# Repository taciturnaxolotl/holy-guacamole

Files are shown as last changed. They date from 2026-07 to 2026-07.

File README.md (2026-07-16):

# Holy Guacamole 🥑



the assembled cad

This is a meltybrain style combat robot that's main weapon is simply its own spinning kinect energy. The BOM is on a google sheet [here](https://docs.google.com/spreadsheets/d/1paAJ0Wakvn5M726pM15FUGLVGKdC47_Wt41PN1yA9PQ/edit?gid=0#gid=0) and the CAD is done in onshape and available [here](https://cad.onshape.com/documents/a046eeb92ff2319e557090a2/w/6774deed54414bae93c63cc1/e/4d0675cbf797ff5c6c8f60bb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)

The canonical repo for this is hosted on tangled over at [`dunkirk.sh/holy-guacamole`](https://tangled.org/dunkirk.sh/holy-guacamole)

| | |
|---|---|
| render 4 | render 3 |
| render 2 | render 1 |

<p align="center">
    
</p>

<p align="center">
    <i><code>&copy; 2026-present <a href="https://dunkirk.sh">Kieran Klukas</a></code></i>
</p>

<p align="center">
  
  
</p>

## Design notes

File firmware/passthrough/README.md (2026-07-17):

# ELRS Passthrough (RP2350)

A **temporary tool firmware** that turns the XIAO RP2350 into a Betaflight-style
serial passthrough bridge, so you can flash or configure the ELRS receiver
wired to `uart0` using the **ExpressLRS Configurator** — no USB-to-serial
adapter, no transmitter, no WiFi.

The receiver is the only thing on `uart0` (GPIO0 = TX → RX's RX, GPIO1 = RX ←
RX's TX, from `../include/hw_pins.h`), which is exactly where a flight
controller sits. This firmware makes the RP2350 answer like one.

## How it works

1. Presents a USB CDC serial port (raw, no console).
2. Emulates the minimal Betaflight CLI that `BFinitPassthrough.py` checks:
   `#`, `get serialrx_provider|inverted|halfduplex|rx_spi_protocol`, `serial`,
   and `serialpassthrough`.
3. On `serialpassthrough` it becomes a transparent USB↔`uart0` bridge and
   mirrors the host's baud onto `uart0`.
4. The Configurator then sends the ROM training burst + the CRSF
   reboot-to-bootloader command through the bridge, and esptool flashes the
   receiver over the same wire.

Until passthrough is active it does **not** forward `uart0` → USB, so the
receiver's CRSF chatter can't corrupt the CLI handshake.

## Build

```bash
# from repo root, inside the firmware nix shell
nix develop ./firmware --command bash -c \
  'cmake -B firmware/passthrough/build -S firmware/passthrough \
     -DPICO_PLATFORM=rp2350 -DPICO_BOARD=pico2 && \
   cmake --build firmware/passthrough/build -j'
```

Output: `firmware/passthrough/build/elrs_passthrough.uf2`.

## Use it

1. **Flash the tool** (reboots the running board into BOOTSEL automatically):
   ```bash
   picotool load -x firmware/passthrough/build/elrs_passthrough.uf2
   ```
2. Open the **ExpressLRS Configurator**, pick your receiver target
   (e.g. BetaFPV 2.4GHz RX), Flashing Method = **BetaflightPassthrough**,
   select the RP2350's serial port, and Flash. (Or use it just to open the
   web/settings if you only want to reconfigure.)
3. **Restore the flight firmware** when done:
   ```bash
   picotool load -x firmware/build/holy_guacamole.uf2
   ```

## Notes

- This image is standalone; it never runs the flight-control loop.
- Baud is followed live via `tud_cdc_line_coding_cb`, so esptool baud changes
  are handled.
- Verified to build and enumerate; the esptool handshake is best confirmed by
  an actual flash attempt against the receiver.

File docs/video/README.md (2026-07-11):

# Holy Guacamole — explainer video

A 3Blue1Brown–style explainer on how meltybrain combat robots work, built in
Motion Canvas. Voiceover-driven, so timing is intentionally loose.

## Run it

```bash
bun install
bun start      # Motion Canvas editor at http://localhost:9000
```

Scrub the timeline in the editor; render from there.

## How it's built

The whole video is **one continuous scene** (`src/scenes/main.tsx`). There are
no cuts. A single persistent robot and a camera-able `world` are handed from
beat to beat, and each beat *transforms* what's on screen rather than replacing
it. That continuity is the 3b1b feel.

- `src/theme.ts` — Manim palette (near-black stage, signature blue, warm
  yellow for "look here"). Fonts are placeholder stacks — swap before final render.
- `src/lib.tsx` — the `Stage` (view + world + robot + a `shared` handoff bag),
  camera helpers (`zoomTo`, `resetCamera`), and builders (`tex`, `label`, `vector`).
- `src/components/MeltyRobot.tsx` — the robot as a minimal stroked diagram.
- `src/beats/*.tsx` — the seven beats, in order.

## The arc (`src/beats/`)

1. `intro` — the melty pops in and starts spinning; "this is a melty"
2. `weapon` — the whole body is the weapon; no constant forward
3. `problem` — a body-fixed heading vector; "forward" turns with the robot
4. `translation` — kick a motor at the same heading each spin; kicks → a glide
5. `centrifugal` — camera glides to a rim sensor; a = ω²r → ω → θ = ∫ω dt
6. `drift` — a naive integrator's estimate lags; live error readout climbs
7. `solution` — an EKF's belief (bell curve) predicts, then sharpens on the
   sensors until the estimate locks onto the true heading

Reorder or trim beats in `main.tsx`. To add one, drop a
`function* name(s: Stage)` in `src/beats/` and slot it into the sequence.

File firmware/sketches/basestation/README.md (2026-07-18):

# Basestation RF Beacon (Arduino)

A stationary ESP-NOW transmitter for the meltybrain RSSI heading system. It
does one thing: broadcast packets as fast as the radio allows so the spinning
robot can measure their RSSI and derive heading from the phase.

## What it is (and isn't)

- **Is:** a dumb beacon. WiFi + antenna + power, nothing else.
- **Isn't:** it does **not** read RSSI, does **not** connect to an ELRS
  receiver, and has **no** UART. All RSSI measurement and heading math happen
  on the robot (`esp-rssi/`).

## Hardware

- **Board:** Seeed XIAO ESP32-C6
- Just needs power and its antenna. No other wiring.
- The onboard user LED (GPIO15) heartbeats ~1 Hz while running, so a blinking
  LED means the basestation is powered and beaconing.
- Just needs power and its antenna. No other wiring.

## Protocol

ESP-NOW broadcast on channel 1, no encryption, no ACK:

- Payload: `magic` byte (`0xB6`) + rolling `uint32` sequence counter
- The payload content is irrelevant to the heading math — that only uses the
  **received RSSI**. The sequence number is purely for drop detection.

Channel and magic byte must match the robot receiver in `esp-rssi/`.

## Flashing (Arduino IDE)

1. Install the **ESP32 boards package** (Boards Manager → "esp32" by
   Espressif). Any recent version works for the beacon.
2. Open `basestation.ino`.
3. Select board **ESP32C3 Dev Module** (or "XIAO_ESP32C3").
4. Select the serial port, then Upload.

Or with `arduino-cli` (from this sketch folder):

```bash
arduino-cli compile --fqbn esp32:esp32:esp32c3 .
arduino-cli upload  --fqbn esp32:esp32:esp32c3 -p <PORT> .
```

## Where it sits in the system

```
[ basestation ] --ESP-NOW broadcast--> [ robot ESP32-C3 (esp-rssi) ]
   (this repo)                              measures RSSI per packet,
                                            runs heading pipeline,
                                            sends stats to RP2350 over UART
```

The ELRS control link is entirely separate and lives on the RP2350 — the
basestation has nothing to do with it. See `docs/firmware.md` for the full
system layout.

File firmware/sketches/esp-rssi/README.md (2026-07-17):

# ESP32-C3 RSSI Heading Receiver (Arduino)

Onboard the spinning robot. Receives beacon packets via ESP-NOW broadcast,
measures the **received signal strength of each packet** (which rises and falls
once per revolution as the robot spins), runs autocorrelation + PLL heading
estimation, and streams results over UART to the RP2350 flight controller.

The heading signal is the radio's measured RSSI of the received packet, not
anything carried in the payload.

## Requirements

- **ESP32 Arduino core 3.0 or newer.** The receive callback needs the
  `esp_now_recv_info_t` signature to read per-packet RSSI (`rx_ctrl->rssi`).
  Core 2.x only exposes the MAC + payload and cannot read RSSI here.

## Hardware

- **Board:** ESP32-C3 (Seeed XIAO ESP32-C3 or any ESP32-C3)
- **UART TX:** GPIO4 → RP2350 GPIO23/SWDIO
- **UART RX:** GPIO5 ← RP2350 GPIO24/SWDCK
- **Baud rate:** 115200 (Serial1)

## Sketch layout

Arduino compiles every `.c`/`.cpp` in the sketch folder, so the ported RSSI
pipeline lives right alongside the sketch:

```
esp-rssi/
  esp-rssi.ino        # WiFi + ESP-NOW + UART glue
  rssi_heading.c/.h   # pipeline top level: interp + autocorr + edge PLL
  rssi_interp.c/.h    # resample RSSI onto a uniform time grid
  autocorr.c/.h       # rotation-period acquisition
  edge_pll.c/.h       # edge-triggered phase lock
```

## UART protocol

Binary frames at ~100 Hz:

```
[0x55 0xAA] [theta_f32] [omega_f32] [locked_u8] [rssi_i8]
  header      rad [0,2pi)  rad/s       0/1          dBm
```

Total: 12 bytes per frame.

## Flashing (Arduino IDE)

1. Install the **ESP32 boards package** 3.0+ (Boards Manager → "esp32").
2. Open `esp-rssi.ino`.
3. Select board **ESP32C3 Dev Module** (or "XIAO_ESP32C3"), pick the port,
   Upload.

Or with `arduino-cli` (from this sketch folder):

```bash
arduino-cli compile --fqbn esp32:esp32:esp32c3 .
arduino-cli upload  --fqbn esp32:esp32:esp32c3 -p <PORT> .
```

The USB serial prints 1 Hz diagnostics (lock state, omega, dropped beacons);
the heading frames go out on Serial1 to the RP2350.

## Transmitter Side

The stationary basestation (`basestation/`) broadcasts beacon packets on
ESP-NOW channel 1, no encryption. Each packet is a `{magic=0xB6, seq}` struct;
this receiver rejects anything without the magic byte and uses `seq` only to
count dropped packets. Channel and magic byte must match on both ends.

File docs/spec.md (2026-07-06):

# Holy Guacamole — Carrier PCB Specification

**Document status:** Draft v1.3c — updated to match current `circuit.py` Rev A schematic: solder-down ELRS receiver `U7`, 3S-ready VBUS, protection diodes documented  
**Robot:** Holy Guacamole — 1lb meltybrain antweight, MRCA full-combat  

---

## Overview

The carrier PCB is a purpose-built board for a Seeed XIAO RP2350 module. It is **not** a bare-RP2350 compute board: the XIAO provides the RP2350, flash, USB, crystal, and onboard 3.3V regulator. The carrier provides power conditioning, sensors, connectors, and robot-specific IO.

Primary carrier jobs:

- Mount the XIAO RP2350 flat as an SMD/castellated module; no XIAO pin headers.
- Generate a local regulated 5V rail from the switched LiPo bus (2S nominal, 3S-ready to 12.6V) using an AP63205 fixed-5V buck regulator.
- Use the XIAO 3.3V rail for IMUs, the SPI-loaded chip-select latch, analog sensing, and control logic; power the solder-down BetaFPV ELRS Lite receiver (`U7`) from the carrier 5V rail per its vendor spec.
- Route SPI to one inner LSM6DSV320X 6-axis/high-G IMU and two outer H3LIS331DL high-G accelerometers.
- Use a SN74HC595PWR SPI-loaded latch for IMU chip-selects and SK9822 LED-output enable; firmware blanks the latch outputs while shifting a new select byte.
- Connect to the Repeat AM32 Dual Brushless Drive ESC using two direct bidirectional DSHOT/EDT lines.
- Keep independent battery voltage sensing on the carrier.
- Rely on AM32 bidirectional DSHOT / EDT for motor eRPM/current/voltage telemetry; no external Kelvin shunt in Rev A.
- Provide a dedicated orange 2-3S TinySLED meltybrain heading output using XIAO edge pin D1/A1 and one MOSFET low-side switch; no underside XIAO GPIOs are used for runtime IO.
- Retain chained top/bottom SK9822 RGB status LEDs for boot/error/mode indication and expose only essential VBAT/SWD/GND test pads.

The PCB mounts near the chassis centre. Final IMU coordinates must be measured from the actual chassis rotation centre and copied into firmware calibration constants.

---

## Current schematic reference designators

These names match the current SKiDL schematic in `circuit.py`.

| Ref | Function |
|---|---|
| `U1` | Seeed XIAO RP2350 SMD module |
| `U2` | AP63205 fixed 5.0V buck regulator |
| `U3` | SN74HC595PWR SPI-loaded chip-select / LED-enable latch |
| `U4` | LSM6DSV320XTR inner 6-axis / high-G IMU |
| `U5`, `U6` | H3LIS331DLTR outer high-G accelerometers |
| `U7` | BetaFPV ELRS Lite receiver, solder-down module footprint |
| `U8`, `U9` | SN74AHCT1G125 3.3V-to-5V SK9822 data/clock buffers |
| `U10`, `U11` | SK9822-EC20 2×2mm addressable status LEDs, top and bottom chained pair |
| `Q1` | AO3402 low-side MOSFET for orange TinySLED heading LED |
| `J1` | Switched 2S/3S LiPo / VBUS carrier power input |
| `J2` | External orange 2-3S TinySLED heading LED connector |
| `J4` | Repeat AM32 dual ESC signal connector |
| `D2` | SMAJ15CA bidirectional TVS across VBUS at power entry |
| `D3`, `D4` | PESD5V0V1BB ESD clamps on DSHOT1/DSHOT2 at J4 |

`J3` piezo and `J5` from older revisions are retired and not present in the current Rev A schematic. The older `J6` receiver fly-lead connector is replaced by the solder-down `U7` receiver footprint.

---

## Physical constraints

| Parameter | Value |
|---|---|
| Board shape | Rectangular with rounded corners |
| Board dimensions | **40mm × 50mm** (width × length) |
| Front direction | 50mm axis is front-to-back; front = top edge in KiCad |
| Max board thickness | 1.0mm preferred; standard 1.6mm may violate chassis Z budget |
| Max component height above board | 2.5mm nominal, set by XIAO module height |
| Mounting | 4× M3 brass heat-set inserts in chassis, M3×6 SHCS from below; holes at four corners inset ~2.5mm from edges |
| Connector exits | J2 heading LED on front (top) edge; J1 power and J4 ESC signal on rear (bottom) edge; all via 26AWG silicone fly-leads on compact non-relief 0.25sqmm SolderWire pads, epoxied after soldering; 16AWG stays in the off-board battery/switch/ESC loop and never lands on the carrier |
| Operating temperature | 0–60°C ambient expectation, with local motor/ESC heating nearby |
| Vibration/impact | Extreme; reinforce heavy/tall components and wire exits with epoxy or strain relief |

### Board coordinate system

KiCad origin at top-left corner of the 40×50mm rectangle. Board center is at (20mm, 25mm). The +Y axis points toward the rear edge; the front/heading edge is at Y=0.

Mounting hole centers (4× M3):

| Hole | X (mm) | Y (mm) |
|---:|---:|---:|
| MH1 | 2.5 | 2.5 |
| MH2 | 37.5 | 2.5 |
| MH3 | 2.5 | 47.5 |
| MH4 | 37.5 | 47.5 |

### IMU placement on rectangular board

The 40×50mm rectangle provides ample clearance for the original IMU radii. All three IMU centroids fit well within the board outline with room for solder mask, routing, and connector pads.

Rev A layout rule:

- Board center at (20, 25) is the rotation reference point.
- Place IMUs at the nominal radii and angles listed below.
- Firmware must use the **measured** post-layout IMU coordinates, not just nominal values from this document.

---

## Module: Seeed XIAO RP2350

**Reference:** `U1`  
**Datasheet / getting started:** https://wiki.seeedstudio.com/xiao_rp2350_getting_started/

| Parameter | Value |
|---|---|
| Dimensions | 21 × 17.5 × 2.5mm |
| Mounting | Castellated SMD pads, soldered flat to carrier; no pin headers |
| Mechanical retention | Small epoxy fillet at four corners after soldering |
| CPU | RP2350, dual Cortex-M33 @ 150MHz, hardware FPU |
| Flash | 4MB W25Q32 onboard; no carrier flash required |
| Crystal | 12MHz onboard; no carrier crystal required |
| 5V input | XIAO `5V/VBUS` pad fed from carrier AP63205 5V rail |
| 3.3V output | XIAO 3.3V rail powers carrier logic/sensors; do not exceed XIAO 3.3V output budget |
| USB-C | Onboard; use for bench programming/config, not combat field wiring |
| SWD | Break out SWDIO/SWDCLK/GND to test pads |

Firmware workload intent:

| Core | Responsibility |
|---|---|
| Core 0 | IMU SPI DMA / sensor fusion / heading EKF / RPM estimation |
| Core 1 | CRSF, DSHOT/EDT, drift control loop, telemetry/status |

---

## Power architecture

Rev A keeps an independent controller buck regulator. The Repeat AM32 dual ESC BEC is **not connected** to the carrier 5V rail.

```text
2S LiPo (3S-ready bus)
  -> Fingertech / main switch
      -> switched battery bus
          -> Repeat AM32 dual ESC power pads
          -> carrier J1 VBUS/GND
              -> D2 SMAJ15CA TVS clamp at power entry
              -> AP63205 fixed 5.0V buck
                  -> 5V rail
                      -> XIAO 5V/VBUS pad
                      -> chained top/bottom SK9822 status LEDs + AHCT buffers
                      -> U7 BetaFPV ELRS Lite receiver 5V pad (solder-down)
                  -> XIAO onboard 3.3V regulator
                      -> LSM6DSV320X + H3LIS331DL IMUs
                      -> SN74HC595 chip-select latch
                      -> analog clamps / control logic
              -> J2 pin 1 TinySLED VBUS feed
                  -> external orange 2-3S TinySLED
                  -> J2 pin 2 HEAD_SW
                  -> Q1 AO3402 low-side switch to GND
```

### ESC BEC policy

The Repeat AM32 Dual ESC includes a 5V BEC, but Rev A leaves it isolated. Do **not** tie the ESC BEC directly to the carrier AP63205 5V rail.

Reasons to keep the carrier buck in Rev A:

- Known 5V source on the controller board.
- Better controller independence if the ESC resets or current-limits hard.
- Avoids importing motor-switching/BEC noise into IMU and analog domains until measured.
- Simpler debugging: battery into `J1` means carrier power is deterministic.

Possible Rev B change:

- Remove/DNP AP63205 buck and use ESC BEC only, **or** add a solder-jumper / ideal-diode power selector.
- Before doing that, confirm ESC BEC current rating, voltage tolerance, startup behavior, and noise under motor load.

### Buck converter: AP63205

**Reference:** `U2`  
**Part:** Diodes Inc. AP63205WU-7, fixed 5.0V, LCSC `C2071056`

| Parameter | Value |
|---|---|
| Package | TSOT-23-6 |
| Input voltage | 3.8–32V part capability; design VBUS is 2S LiPo 6.0–8.4V nominal, 3S-ready to 12.6V |
| Output voltage | Fixed 5.0V; FB pin connects to 5V, no feedback divider |
| Output current | 2A device rating; actual board load is far lower unless external LEDs are overdriven |
| Inductor | 4.7uH, Bourns SRP4020TA-4R7M / LCSC `C2041623` in current schematic |

Required local passives in current schematic:

| Ref | Value | Function |
|---|---|---|
| `C1` | 22uF | VBUS input bulk, rated at least 25V |
| `C2` | 100nF | High-frequency VIN bypass close to U2 VIN/GND |
| `C3` | 100nF | Bootstrap capacitor from BST to SW |
| `C4`, `C5` | 22uF each | 5V output capacitance near L1/U2 return path |
| `C6` | 10uF | 3.3V bulk near sensor/control load cluster |

Power-entry protection in current schematic:

| Ref | Part | Function |
|---|---|---|
| `D2` | SMAJ15CA, LCSC `C110044` | Bidirectional 15V-standoff TVS across VBUS/GND at J1; clamps below the AP63205 32V input rating with margin for 3S |

Layout requirements:

- Place `C1`/`C2` tight to U2 VIN/GND.
- Keep the `SW` copper area compact.
- Keep the buck switch node and inductor away from IMUs, CRSF, VBAT sense, and heading LED control/test nodes.
- Use wide copper for VBUS and 5V where LED pulses can draw peak current.

---

## IMU array: 1× LSM6DSV320X + 2× H3LIS331DL

**References:** `U4`, `U5`, `U6`  
**Parts:** `U4` STMicroelectronics LSM6DSV320XTR, LGA-14, LCSC `C26633007`; `U5`/`U6` STMicroelectronics H3LIS331DLTR, LGA-16L 3×3mm, LCSC `C2655074`

### Placement geometry

All three IMUs share SPI SCK/MOSI/MISO and use independent active-low chip-selects generated by `U3` SN74HC595PWR. The latch is loaded over the same SPI MOSI/SCK nets while its outputs are blanked by `SEL_OE_N`.

Nominal geometry intent:

| Sensor | Nominal angle | Nominal radius | Centroid (mm from board center) | Rationale |
|---|---:|---:|---|---|
| IMU-A | 0° / +X right | 12mm | (+12, 0) → KiCad (32, 25) | Inner LSM6DSV320X reference sensor with gyro and lower G loading |
| IMU-B | 90° / +Y rear | 18mm | (0, +18) → KiCad (20, 43) | Orthogonal outer H3LIS331DL sensor for X/Y decomposition |
| IMU-C | 210° | 18mm | (-15.6, -9) → KiCad (4.4, 16) | Asymmetric outer H3LIS331DL placement breaks heading singularities |

G loading at 4000RPM:

| Radius | Centrifugal G |
|---:|---:|
| 12mm | ~216G |
| 18mm | ~324G |

All IMU centroids are at least 4mm from the nearest board edge on the 40×50mm rectangle, providing comfortable clearance for solder mask, silkscreen, and routing. If the outer radius changes, update the firmware measurement model.

### IMU configuration

| Parameter | IMU-A LSM6DSV320X | IMU-B/IMU-C H3LIS331DL |
|---|---|---|
| Sensor role | Inner 6-axis/high-G reference with gyro | Outer high-G accelerometers |
| Interface | SPI mode 0, shared bus | SPI mode 0, up to 10MHz |
| Output data rate | Firmware-selected high-rate accel/gyro mode | 1000Hz target |
| Axes used | Gyro + X/Y acceleration for heading estimation | X/Y in-plane; Z available but not central to heading model |
| Support pins | SDx and SCx tied to GND; INT/aux pins unused/NC | Reserved pin 10 to GND, pin 15 to Vdd; INT pins unused/NC |

### Decoupling

Current schematic has:

- `C8` and `C11` = 100nF local capacitors for IMU-A LSM6DSV320X `VDD` and `VDDIO`.
- `C9`, `C10` = 100nF local capacitors for IMU-B/IMU-C H3LIS331DL `Vdd`.
- `C6` and `C13` = 10uF 3.3V bulk capacitors for the sensor/control cluster (C13 at the far end of the IMU spread).

ST guidance for these IMUs calls for local 100nF bypassing at each supply pin plus nearby bulk capacitance. In layout, keep `C6` close to the IMU/3.3V/latch cluster and place `C13` near whichever outer IMU (U5/U6) lands farthest from C6, so the radial 3V3 route stays stiff at both ends.

### SPI wiring

| Signal | Source | Notes |
|---|---|---|
| `SPI_SCK` | XIAO D8/GPIO2 | Shared SPI clock |
| `SPI_MOSI` | XIAO D10/GPIO3 | Shared MOSI |
| `SPI_MISO` | XIAO D9/GPIO4 | Shared MISO |
| `CS_A` | SN74HC595 QA / pin 15 | IMU-A active-low chip-select |
| `CS_B` | SN74HC595 QB / pin 1 | IMU-B active-low chip-select |
| `CS_C` | SN74HC595 QC / pin 2 | IMU-C active-low chip-select |

All three IMUs run in 4-wire SPI mode; I2C is not used anywhere on the carrier. With two identical H3LIS331DL parts, I2C would not work anyway: the part exposes only one SA0 address-select level, so both outer sensors would collide on the same bus address. Per-device SPI chip-selects from the SN74HC595 avoid that entirely, and the H3LIS SDO/SA0 pads are used as SPI data outputs, not address straps.

`R6`, `R7`, and `R8` are 33Ω series resistors from each IMU SDO to shared MISO for ringing and bus-contention limiting.

Each CS line has a 10kΩ pull-up (`R3`, `R4`, `R5`) so the IMUs remain deselected while the RP2350 boots or while the SN74HC595 outputs are high-Z/blanked.

`R18` (100kΩ) pulls `SPI_SCK` low so the shared clock idles low even while the RP2350 tri-states the bus at boot/reset. The bus runs SPI Mode 0 specifically so a deselected H3LIS331DL — which reverts to I2C and reads `SPI_SCK`/`SPI_MOSI` as SCL/SDA when its CS is high — never sees an I2C START (SDA falling while SCL high) on foreign traffic. See open item 10.

### IMU readout timing

Rev A uses one shared `SPI_MISO` net, so firmware must select **only one IMU at a time**. Do not assert `CS_A`, `CS_B`, and `CS_C` simultaneously on this hardware: all selected IMUs would drive the same MISO net through the 33Ω resistors, causing contention and invalid data.

Timing budget at 10MHz SPI:

| Operation | Approximate time |
|---|---:|
| H3LIS331DL X/Y burst read: 1 address byte + 4 data bytes = 40 bits | ~4us per outer IMU |
| Three ideal sequential IMU reads | ~12us |
| SN74HC595 select-byte shift: 8 bits plus `SEL_LAT` pulse | <1us at 10MHz plus firmware overhead |
| Practical three-IMU read set with latch CS management | ~15-30us depending on firmware gaps |
| Angular skew at 4000RPM for 30us | ~0.72deg |

Firmware requirements:

- Maintain a cached 8-bit SN74HC595 latch image. Update it only while `SEL_OE_N` is high so latch outputs are high-Z and the external pull-ups keep all CS/LED-enable nets inactive.
- Keep exactly one IMU CS low during each SPI data transaction.
- Timestamp the read set and, if needed, compensate fixed read skew in the estimator. Expected Rev A skew is below other likely error sources such as IMU placement tolerance and accelerometer nonlinearity.
- Parallel-MISO PIO readout is a Rev B optimization only. It would require routing `MISO_A`, `MISO_B`, and `MISO_C` to separate direct RP2350 GPIOs, while sharing SCK/MOSI/CS timing. It is not supported by the current edge-pin-only Rev A schematic.
- Parallel MISO removes bus readout skew but does not synchronize the IMUs' internal sample clocks; data-ready timing still matters if sample simultaneity becomes a limiting error source.

### Axis orientation convention

Mount each chip so:

- chip X axis points radially outward from the rotation centre;
- chip Y axis points tangentially in the defined positive rotation direction.

Verify against the H3LIS331DL datasheet axis diagram before fabrication. Wrong axis orientation is hard to debug after assembly.

---

## SPI-loaded chip-select latch

**Reference:** `U3`  
**Part:** SN74HC595PWR, LCSC `C273642`

The XIAO edge pads are pin-limited, so the carrier uses a SPI-loaded serial-in/parallel-out latch instead of a SPI GPIO expander. It consumes no dedicated MISO line and uses only the shared `SPI_MOSI`/`SPI_SCK` plus two direct GPIO controls: `SEL_OE_N` and `SEL_LAT`.

| Latch function | Signal |
|---|---|
| Output blanking from XIAO | `SEL_OE_N`, XIAO D2/A2/GPIO42 -> U3 `/OE` |
| Latch clock from XIAO | `SEL_LAT`, XIAO D3/A3/GPIO43 -> U3 `RCLK` |
| Serial data | `SPI_MOSI` -> U3 `SER` |
| Shift clock | `SPI_SCK` -> U3 `SRCLK` |
| IMU-A select | `CS_A` |
| IMU-B select | `CS_B` |
| IMU-C select | `CS_C` |
| SK9822 level-shifter output enable | `LED_OE_N`, from SN74HC595 QD / pin 3 |

Boot-safe pull-ups:

- `R1`: pulls `SEL_OE_N` high so SN74HC595 outputs are high-Z while XIAO boots.
- `R11`: pulls `SEL_LAT` low so startup noise does not latch garbage into the outputs.
- `R2`: pulls `LED_OE_N` high so AHCT LED buffers are disabled while U3 is blanked or uninitialized.
- `R3`/`R4`/`R5`: pull `CS_A`/`CS_B`/`CS_C` high so all IMUs are deselected while U3 outputs are high-Z/blanked.

### Firmware latch protocol

The SN74HC595 has no chip-select input and shares the IMU/status SPI clock and MOSI nets, so firmware must treat latch updates as explicit bus transactions with outputs blanked:

1. Drive `SEL_OE_N` high to put U3 QA-QH high-Z. External pull-ups then force `CS_A`, `CS_B`, `CS_C`, and `LED_OE_N` inactive/high.
2. Shift the desired 8-bit latch image on `SPI_MOSI` using `SPI_SCK`.
3. Pulse `SEL_LAT` high then low to transfer the shifted byte to QA-QH.
4. Drive `SEL_OE_N` low only for the selected IMU or LED update window.
5. Return to a safe all-inactive image and/or drive `SEL_OE_N` high before changing targets.

Latch bit assignment in Rev A:

| SN74HC595 output | Net | Active state | Firmware meaning |
|---|---|---:|---|
| QA / pin 15 | `CS_A` | 0 | Select IMU-A LSM6DSV320X |
| QB / pin 1 | `CS_B` | 0 | Select IMU-B H3LIS331DL |
| QC / pin 2 | `CS_C` | 0 | Select IMU-C H3LIS331DL |
| QD / pin 3 | `LED_OE_N` | 0 | Enable SK9822 AHCT data/clock buffers |
| QE-QH, QH' | NC | — | Leave unused; shift deterministic 1s for inactive outputs |

Firmware safety rules:

- Never enable outputs with more than one of `CS_A`, `CS_B`, or `CS_C` low.
- Keep `LED_OE_N` high during IMU reads and latch changes so normal IMU SPI traffic does not clock garbage into the SK9822.
- Keep all CS lines high while updating the SK9822; only QD/`LED_OE_N` should be low for LED writes.
- Initialize `SEL_OE_N` as a pulled/high GPIO before configuring the SPI peripheral if possible. `R1` provides the hardware fallback during reset.
- Because latch shifting uses the same `SPI_MOSI`/`SPI_SCK` as the IMUs, do not shift a new latch byte while any IMU CS is enabled.

---

## Repeat AM32 dual ESC / DSHOT / EDT

**External ESC:** Repeat AM32 Dual Brushless Drive ESC  
**Carrier connector:** `J4`, one combined signal harness

`J4` pinout:

| Pin | Signal | Notes |
|---:|---|---|
| 1 | GND | ESC signal/battery ground reference |
| 2 | `DSHOT1` | AM32 channel 1 / white signal wire, bidirectional DSHOT + EDT |
| 3 | `DSHOT2` | AM32 channel 2 / yellow signal wire, bidirectional DSHOT + EDT |
| 4 | GND | Second local return / harness strain relief |

XIAO pins:

| Signal | XIAO pin | Series part |
|---|---|---|
| `DS1_IO` -> `DSHOT1` | D4/SDA/GPIO6 | `R12` = 33Ω |
| `DS2_IO` -> `DSHOT2` | D5/SCL/GPIO7 | `R13` = 33Ω |

Requirements:

- Use RP2350 PIO/DMA/timer support; do not bit-bang in a jittery control loop.
- Keep DSHOT lines direct from RP2350-capable GPIOs; do not route through the SN74HC595 latch.
- `D3`/`D4` PESD5V0V1BB bidirectional 5V ESD clamps sit at J4 pins 2/3 to ground, on the connector side of `R12`/`R13`.
- **Firmware must use DSHOT600** for normal bidirectional DSHOT/EDT operation at ~4000–4300RPM. DSHOT300 is allowed only for bench/low-speed testing because the effective bidirectional command/telemetry update rate is marginal near strike RPM.
- Bidirectional DSHOT/EDT returns eRPM and extended telemetry over the same signal wires; no extra telemetry UART is required in Rev A.
- Configure AM32 motor pole count correctly. For a 14-pole outrunner, pole pairs = 7 and mechanical RPM = eRPM / 7. Verify actual motor magnet pole count instead of guessing.
- ESC BEC output is not connected to this carrier in Rev A.

High-current ESC battery and motor phase wiring must not pass through the carrier PCB. The carrier only handles logic-level DSHOT/EDT and its own VBUS feed.

---

## CRSF / ELRS

**Reference:** `U7` — solder-down module footprint (Eyeliner repo landing pattern), no fly-lead connector  
**Receiver:** BetaFPV ELRS Lite Receiver 2.4GHz, Flat Antenna V1.2 variant, https://betafpv.com/products/elrs-lite-receiver

Vendor-listed receiver facts for the selected variant:

| Parameter | Value |
|---|---|
| MCU | ESP8285 |
| Serial output protocol | CRSF |
| Input voltage | 5V |
| Frequency band | 2.4GHz ISM |
| Telemetry RF power | 17mW |
| Size / mass | 11 × 10 × 3mm, 0.46g |
| Antenna | Integrated SMD ceramic antenna |

| U7 pad | Signal | Notes |
|---:|---|---|
| 1 | GND | Receiver ground |
| 2 | 5V | Receiver power from carrier AP63205 5V rail; BetaFPV specifies 5V input |
| 3 | receiver TX/T | Drives carrier `CRSF_RX` -> XIAO D7/GPIO1 |
| 4 | receiver RX/R | Driven by carrier `CRSF_TX` <- XIAO D6/GPIO0 |

CRSF caveat:

- CRSF is normally non-inverted UART at 420000 baud. SBUS is the common inverted-serial trap; Rev A is using CRSF, not SBUS.
- Rev A schematic has no discrete CRSF inverter, which is appropriate for the selected BetaFPV ELRS Lite CRSF output.
- Pad order GND, 5V, TX/T, RX/R is user-confirmed against the Eyeliner landing pattern; re-verify on the physical receiver before soldering and keep the cross-connection: receiver TX -> XIAO RX (`CRSF_RX`), receiver RX <- XIAO TX (`CRSF_TX`).

Receiver placement: soldered directly to the carrier with the antenna end at the board edge nearest the chassis wall; keep the antenna away from copper pours, battery, the buck inductor/switch node, and motor phase wires. Add foam/epoxy support after soldering so impacts do not peel the module pads.

---

## Analog / event inputs

### Battery voltage sense

The carrier keeps an independent battery divider even though the ESC can provide telemetry. This gives pack voltage during bring-up and if ESC telemetry is unavailable.

| Parameter | Value |
|---|---|
| XIAO ADC pin | A0/D0/GPIO40 |
| Net | `VBAT_SNS` |
| Divider high-side | `R9` = 120kΩ from VBUS |
| Divider low-side | `R10` = 33kΩ to GND |
| Filter | `C12` = 100nF to GND |
| ADC voltage at 8.4V pack | ~1.81V |
| ADC voltage at 12.6V 3S full charge | ~2.72V |
| ADC voltage at 6.0V pack | ~1.29V |

Use this for independent low-battery warning and telemetry. Firmware can fuse/compare this with AM32 EDT voltage.

### Current sensing

There is **no INA180 / Kelvin shunt current-sense circuit in Rev A**.

Current/eRPM telemetry path:

- AM32 bidirectional DSHOT provides eRPM feedback per motor.
- AM32 Extended DSHOT Telemetry can provide ESC voltage/current/temperature data when supported/configured.
- ESC current limiting remains local to the ESC.

If future testing shows AM32 current telemetry is insufficient, add an external inline shunt and INA180 in a later revision. Do not route motor current through this carrier PCB.

---

## Status LED: SK9822

**References:** `U10` top / first in chain, `U11` bottom / second in chain  
**Part:** SK9822-EC20, 2×2mm, LCSC `C2909059`

The RGB status LEDs are intentionally retained in Rev A. They are small top/bottom-visible status/debug indicators, not the primary meltybrain heading indicator.

| Parameter | Value |
|---|---|
| Interface | APA102-compatible SPI-style data/clock |
| Power | 5V rail |
| Data buffer | `U8` SN74AHCT1G125, 3.3V input to 5V output |
| Clock buffer | `U9` SN74AHCT1G125, 3.3V input to 5V output |
| Output-enable control | `LED_OE_N` from SN74HC595 QD, pulled up by `R2` |
| Local bypass | `C16` = 100nF at U10, `C17` = 100nF at U11 |
| Worst-case LED current budget | ~61mA full white per LED, ~122mA for both |

Keep this subsystem populated for Rev A unless board area becomes impossible. It provides multi-color boot/error/mode indication on both sides of the robot without consuming extra direct XIAO GPIOs. Because the SK9822 chain shares the IMU SPI SCK/MOSI nets before the AHCT buffers, firmware must keep `LED_OE_N` disabled during normal IMU/latch SPI traffic and only enable the buffers when intentionally updating status LEDs. This avoids accidental LED updates during high-rate IMU bursts. Firmware must send two LED frames; duplicate the frame if top and bottom should show the same colour.

State/color mapping is firmware-defined. Suggested defaults:

| State | Colour | Pattern |
|---|---|---|
| Boot / no RC signal | White | Slow pulse |
| RC signal acquired, not spinning | Yellow | Solid |
| Spinning up | Yellow | Fast pulse |
| Heading lock acquired | Green | Solid |
| Drifting / manual correction | Cyan | Solid |
| Low battery | Red | Fast blink |
| Impact detected | Orange | Single flash |
| RC failsafe | Red | Solid |

---

## Meltybrain heading LED driver

**Connector:** `J2`  
**External module:** orange Tiny's LEDs 2-3S Micro LED / equivalent 2S-rated orange LED module  
**Driver topology:** module powered from switched 2S `VBUS`, low-side MOSFET switch controlled by XIAO edge pin D1/A1.

This is the primary visible heading marker. It is separate from the SK9822 status LED. Because the robot body will be printed in green filament, the default heading marker is a fixed orange LED module rather than a green or RGB heading LED.

At 4000RPM:

```text
1 revolution = 15ms
1 degree ~= 41.7us
100us pulse ~= 2.4 degree arc
300us pulse ~= 7.2 degree arc
500us pulse ~= 12 degree arc
```

Firmware must phase-lock the strobe to the estimated heading and start tuning with ~300-500us pulses. The LED must be off by default at boot/reset. Strobe generation must be a bounded hardware-timed one-shot using RP2350 PIO/timer logic with a hard maximum on-time; the main control loop should only arm/configure bounded pulses, not hold the GPIO high directly. This protects the TinySLED from overheating if firmware hangs or misses a state transition.

`J2` pinout:

| Pin | Signal | Notes |
|---:|---|---|
| 1 | `VBUS` | Switched 2S battery feed to TinySLED `+` pad |
| 2 | `HEAD_SW` | TinySLED `-` pad; MOSFET-switched return |

Driver parts:

| Function | Part | Notes |
|---|---|---|
| GPIO drive | XIAO D1/A1/GPIO41 | Edge/castellated pad only; avoids underside GPIO dependency |
| Gate stopper | `R16` = 100Ω | Between D1/A1 and Q1 gate |
| Gate pulldown | `R17` = 100kΩ | Holds LED off during boot/reset |
| Low-side switch | `Q1` AO3402 | Drain to `HEAD_SW`, source to GND |

Important notes:

- The selected 2-3S TinySLED module is expected to include its own current limiting; do not add a series LED resistor unless the selected module variant requires it.
- The heading LED current loop is `VBUS -> J2 pin 1 -> TinySLED -> J2 pin 2 -> Q1 -> GND`; route it away from IMU supplies and battery ADC routing.
- Keep the SK9822 RGB status LED for boot/error/mode colors; the TinySLED is the high-brightness heading marker only.

## Test points

Expose the following as 1mm solderable pads with silkscreen labels.

| Label | Signal | Why |
|---|---|---|
| `TP_VBAT` | `VBAT_SNS` | Battery divider output / ADC calibration |
| `TP_SWDIO` | `SWDIO` | Picoprobe/SWD debug data |
| `TP_SWDCK` | `SWDCK` | Picoprobe/SWD debug clock |
| `TP_GND` | GND | Scope/logic-analyzer/SWD ground reference |

---

## Pin assignment summary

| XIAO pad | Current signal | Direction | Notes |
|---|---|---|---|
| D0/A0/GPIO40 | `VBAT_SNS` | ADC in | Battery voltage divider |
| D1/A1/GPIO41 | `HEAD_LED` | GPIO out | Orange TinySLED MOSFET gate drive |
| D2/A2/GPIO42 | `SEL_OE_N` | GPIO out, active-low enable | Blanks/enables SN74HC595 latch outputs |
| D3/A3/GPIO43 | `SEL_LAT` | GPIO out | Latches the shifted SN74HC595 select byte |
| D4/SDA/GPIO6 | `DS1_IO` | bidir | AM32 channel 1 DSHOT/EDT via 33Ω |
| D5/SCL/GPIO7 | `DS2_IO` | bidir | AM32 channel 2 DSHOT/EDT via 33Ω |
| D6/TX/GPIO0 | `CRSF_TX` | UART out | To ELRS receiver |
| D7/RX/GPIO1 | `CRSF_RX` | UART in | From ELRS receiver |
| D8/SCK/GPIO2 | `SPI_SCK` | SPI out | IMUs, SN74HC595 latch, SK9822 buffer input |
| D9/MISO/GPIO4 | `SPI_MISO` | SPI in | IMU data return only |
| D10/MOSI/GPIO3 | `SPI_MOSI` | SPI out | IMUs, SN74HC595 latch, SK9822 buffer input |
| D11 | NC | — | Underside pad left unused in Rev A |
| D12 | NC | — | Underside pad left unused in Rev A |
| SWDIO | `SWDIO` | debug | Test pad |
| SWDCLK | `SWDCK` | debug | Test pad |
| 5V/VBUS | 5V | power in | Carrier AP63205 buck output; also powers the BetaFPV ELRS Lite receiver through the `U7` solder-down pads |
| 3V3 / 3V3_OUT | 3V3 | power out | Powers IMUs, latch, analog refs, and 3.3V logic |
| GND | GND | power | Common ground |

Runtime IO intentionally stays on XIAO edge/castellated pads. Underside GPIO/control pads are left NC unless a later revision explicitly accepts the assembly/rework tradeoff.

---

## Mass budget — carrier PCB, rough order

These are planning numbers only; measure final PCB and populated assembly.

| Component group | Qty | Estimated total |
|---|---:|---:|
| XIAO RP2350 module | 1 | ~3.0g |
| LSM6DSV320X + H3LIS331DL IMUs | 3 | ~0.15g |
| AP63205 buck IC + inductor + passives | 1 set | ~0.5g |
| SN74HC595 latch + pullups/decoupling | 1 set | ~0.1g |
| 2× SK9822 + AHCT buffers + passives | 1 set | ~0.15g |
| BetaFPV ELRS Lite receiver soldered on `U7` | 1 | ~0.5g |
| Orange TinySLED MOSFET gate driver | 1 set | ~0.05g, not including external LED/module/wires |
| Battery sense passives and essential test pads | — | ~0.1g |
| PCB substrate, 40×50mm, 1.0mm FR4 | 1 | ~3.0–3.3g |
| Solder + epoxy/strain relief | — | ~0.3g |
| **Carrier PCB total** |  | **~7.7g estimate** |

Removed versus older spec:

- No INA180 current-sense amplifier.
- No 5mΩ external shunt in the carrier BOM.
- No separate two-ESC signal connector pair.
- No protected piezo input; removed from Rev A.

External/not included in carrier mass:

- Repeat AM32 Dual Brushless Drive ESC.
- External orange 2-3S TinySLED module and its wires.
- Piezo disc bonded to chassis.

---

## Fabrication notes

- **Layer count:** 2-layer is acceptable if layout keeps a clean ground return and compact buck loop; 4-layer is optional for easier grounding and routing.
- **Copper weight:** 1oz outer layers standard.
- **Surface finish:** ENIG recommended for LGA-16L IMUs and XIAO castellations; avoid HASL for the LGA pads.
- **Min trace/space:** 0.1mm / 0.1mm target for LGA fanout.
- **Soldermask:** both sides.
- **Assembly:** paste + reflow/hot air required for LGA-16L. Do not attempt iron-only assembly of the IMUs.
- **Stencil:** order a stainless stencil with the PCB.
- **Reinforcement:** epoxy fillets at XIAO corners and strain relief on all fly-lead exits after electrical test.

---

## Open items before fab

1. **Final IMU coordinates**  
   Board outline is now 40×50mm rectangular. Nominal IMU centroids are listed in the IMU placement table. After assembly, measure actual positions and update firmware constants.

2. **BetaFPV ELRS Lite receiver integration**  
   The receiver solders directly to the carrier `U7` footprint (pad order GND, 5V, TX/T, RX/R). Before soldering, re-verify the physical pad order on the actual receiver, plus firmware target/version, binding phrase, packet rate, telemetry ratio, and failsafe behavior.

3. **AM32 configuration**  
   Set profile `AM32_RR_ROBOT_DUAL_ESC_F421`, bidirectional drive, bidirectional DSHOT/EDT, current limits, motor direction, and correct motor pole count.

4. **Heading LED/module selection**  
   Confirm the exact orange 2-3S TinySLED / LED module variant, pad polarity, and mounting. Validate that it remains visible through/around the green chassis material; add a clear/frosted window or diffuser if needed. Confirm it has onboard current limiting; otherwise add a suitable series limiter.

5. **Heading strobe firmware safety**  
   Implement the TinySLED pulse as a hardware-timed one-shot with a hard maximum on-time. Verify reset/boot keeps Q1 off via `R17`, and verify a firmware hang cannot leave `HEAD_LED` asserted continuously.

6. **ESC BEC characterization**  
   Optional future work only. Measure BEC voltage/current/noise under motor load before considering deletion/DNP of the AP63205 buck.

7. **IMU readout firmware**  
   Implement optimized sequential IMU reads through the SN74HC595 select latch. Keep exactly one IMU selected at a time, update the latch only while `SEL_OE_N` blanks the outputs, and do not use simultaneous-CS reads unless the PCB is revised for separate MISO lines.

8. **IMU placement measurement**  
   After assembly, measure actual IMU centroids and axes relative to chassis centre and store calibration constants in firmware.

9. **Power integrity check**  
   Scope 5V, 3V3, and VBUS during heading LED strobes, DSHOT traffic, and motor spin-up. Ensure TinySLED pulses do not corrupt IMU reads, VBAT ADC readings, or reset the XIAO.

10. **H3LIS331DL shared-bus I2C-listening exposure**  
    The H3LIS331DL has no I2C-disable register bit (CTRL_REG4 = BDU/BLE/FS1/FS0/SIM only); whenever its CS is high it reverts to I2C mode and listens to `SPI_SCK`/`SPI_MOSI` as SCL/SDA. Bus traffic that mimics START + address `0x18/0x19` + W can make a deselected U5/U6 ACK onto MOSI or accept a phantom write into its own config registers.

    **Primary mitigation — SPI Mode 0 (SCK idle-low), no hardware cost.** Every device on the shared bus samples on the rising clock edge and tolerates an idle-low clock, so the bus runs Mode 0: U1 RP2350 master (PL022, all modes), U3 SN74HC595 (rising-edge shift), U4 LSM6DSV320X (datasheet-confirmed Mode 0/3), U5/U6 H3LIS331DL (datasheet-confirmed Mode 0/3), and the U8/U9 AHCT→SK9822 path (rising-edge data latch). In Mode 0 `SPI_SCK` (= SCL to a deselected sensor) idles low and stays stable through every SCK-high phase, and `SPI_MOSI` (= SDA) only transitions while SCK is low. An I2C START requires SDA to fall while SCL is *high*, which therefore never occurs — the deselected sensor's I2C state machine never leaves idle, so no phantom address match or config write is possible. Mode 3 (SCK idle-high) is the exposed case and must not be used.

    **Boot/reset hardening.** `R18` (100kΩ) pulls `SPI_SCK` to GND so SCL is held idle-low even while the RP2350 tri-states the bus before SPI init and during resets — closing the only window where SCK could float high. SCK is the START-critical line, so MOSI does not need pinning.

    **Defense-in-depth (firmware).** Firmware still sets the LSM6DSV320X `IF_CFG` (0x03) `I2C_DISABLE` bit at init (the LSM6DSV320X has this bit; the H3LIS331DL does not) and periodically reads back/verifies the H3LIS config registers. If field testing ever shows corruption despite Mode 0, add per-sensor SCK|CS OR-gate clock gating or move to the Rev B parallel-MISO rework.

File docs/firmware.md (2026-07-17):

# Holy Guacamole — Firmware & Simulator (running doc)

**Document type:** Running engineering doc for the *as-built* firmware and the
SITL digital twin. Updated as code lands.
**Scope:** What is actually implemented in `firmware/`, how to build/test it,
and the simulator fidelity model. For hardware see `spec.md` (carrier PCB) and
`braindump.md` (design research / rationale).

> `spec.md` is the carrier-PCB spec and is not affected by firmware/sim work.
> `braindump.md` is the design/research record and describes *intended* designs
> (some ahead of the code). This doc tracks *what the code does today* and the
> numbers the twin is anchored to.

---

## 0. System layout (three MCUs + the ELRS link)

The robot is not one microcontroller. Three processors and one RC receiver
each own a distinct job; getting the wiring picture right matters because it
determines where things like ELRS configuration actually happen.

```
                          RF (2.4 GHz ELRS)
   pilot's radio  )))  ------------------------->  ELRS receiver
                                                      |  CRSF @ 420000, full duplex
                                                      |  ELRS TX -> XIAO D7/RX (GPIO1)
                                                      |  ELRS RX -> XIAO D6/TX (GPIO0)
                                                      v
   [ basestation ]                            [ RP2350  (XIAO RP2350) ]
   ESP32-C3, stationary                        main flight controller
       |                                        - estimation + control + safety
       | ESP-NOW broadcast                      - DSHOT to ESCs
       | (RF beacon, ch 1)                      - reads ELRS CRSF (uart0)
       v                                        ^
   [ robot ESP32-C3 (esp-rssi) ] --------------/
   measures RSSI of each beacon packet       UART @ 115200 (uart1, pins 23/24)
   as the robot spins, runs the heading      RSSI heading stats -> RP2350
   pipeline, streams stats to the RP2350
```

**Who does what:**

| Unit | Board | Job | Wiring |
|---|---|---|---|
| Basestation | ESP32-C3 (off-board) | Dumb RF beacon; broadcasts ESP-NOW packets as fast as the radio drains | Power + antenna only |
| RSSI sensor | ESP32-C3 (`esp-rssi/`) | Receives beacon, measures per-packet RSSI, runs autocorr+PLL heading pipeline, sends stats to RP2350 | UART → RP2350 uart1 (115200) |
| Flight controller | RP2350 (`firmware/`) | EKF + drift control + safety + DSHOT; consumes ELRS control input and the ESP32-C3 RSSI stats | ELRS on uart0 (GPIO0/1), ESP32-C3 on uart1 |
| RC receiver | ELRS RX | Pilot control link (throttle/sticks) via CRSF | uart0 @ 420000 (see `hw_pins.h`) |

The **ELRS receiver is wired to the RP2350's uart0**, not to either ESP32. The
basestation has no receiver and no UART — it only transmits. The two ESP32-C3s
are different roles on different boards (one off-robot beacon, one on-robot
RSSI sensor).

### Configuring / flashing the ELRS receiver

Because the ELRS RX sits on the RP2350's UART, the RP2350 is where a Betaflight
"serial passthrough" bridge would have to live if you wanted to flash over the
wire. **You don't need that.** Use the receiver's built-in WiFi instead:

1. Power the receiver and leave it ~60 s with no bound TX active.
2. It self-hosts an access point (`ExpressLRS RX`).
3. Connect and browse to `10.0.0.1`.
4. The web UI covers binding phrase, packet rate, TX power, telemetry ratio,
   **and** OTA firmware updates.

That covers every setting a meltybrain build touches, with zero firmware work
on the RP2350.

---

## 1. Status snapshot

| Area | State |
|---|---|
| Math (`linalg`) | implemented, unit-tested |
| Estimation (`ekf`, `meas_model`, `imu_geom`, `imu_convert`) | implemented, tested; **reduced 3-state filter** (see §4) |
| `accel_cal` | **wired** into the shared SI path (`app_sensor_tick_si` → `accel_cal_apply`, outer H3LIS channels); unit-tested + validated end-to-end. No-op until a table is loaded |
| Control (`pid`, `drift`) | implemented; sinusoidal + square modulation |
| Safety (`watchdog`, `rc_health`, `battery`) | implemented; dual-core spinlock watchdog |
| App glue (`control_loop`) | implemented; shared by firmware and sim |
| SITL sim | **hand-rolled plant (Box2D dropped), realistic IMU, scenario harness** — see §7 |
| Drivers (`imu_spi`, `dshot`, `crsf`, `latch`) | in progress |

---

## 2. Build & test quickref

All commands run inside the Nix dev shell.

```bash
# Firmware (RP2350 / Pico 2)
nix develop --command bash -c \
  'cmake -B build -DPICO_PLATFORM=rp2350 -DPICO_BOARD=pico2 && cmake --build build -j'

# Unit tests (host)
nix develop --command bash -c \
  'ctest --test-dir build-tests --output-on-failure'

# Interactive SITL sim (raylib window)
nix develop --command bash -c \
  'cmake -B build-sim -S sim && cmake --build build-sim'
```

### ESP32-C3 boards (basestation + esp-rssi)

These are **Arduino sketches** under `firmware/sketches/`, not part of the
Nix/CMake build. Flash them with the Arduino IDE or `arduino-cli` using the
ESP32 boards package (run from the repo root):

```bash
# basestation (any recent ESP32 core)
arduino-cli compile --fqbn esp32:esp32:esp32c3 firmware/sketches/basestation
arduino-cli upload  --fqbn esp32:esp32:esp32c3 -p <PORT> firmware/sketches/basestation

# esp-rssi (needs ESP32 Arduino core 3.0+ for per-packet RSSI)
arduino-cli compile --fqbn esp32:esp32:esp32c3 firmware/sketches/esp-rssi
arduino-cli upload  --fqbn esp32:esp32:esp32c3 -p <PORT> firmware/sketches/esp-rssi
```

`firmware/sketches/esp-rssi/` keeps the ported RSSI pipeline
(`rssi_heading.c`, `edge_pll.c`, `rssi_interp.c`) in the sketch folder so
Arduino compiles them automatically.

Tests live in `firmware/tests/`: `test_linalg`, `test_ekf`, `test_drift`,
`test_sim_convergence`, and `test_scenarios` (closed-loop digital-twin
scenarios). All build with the host compiler under `-Wall -Wextra -Werror`.

---

## 3. Repo / module map

```
firmware/src/
  main.c                 app entry, dual-core bringup, arming logic
  app/control_loop.{c,h} HW-free per-tick logic shared by firmware AND sim:
                         app_sensor_tick_si (EKF) + app_control_tick (drift)
  estimation/
    ekf.{c,h}            reduced 3-state EKF (theta, omega, alpha)
    meas_model.{c,h}     7-row measurement model + saturation flags
    imu_geom.{c,h}       sensor positions + shared physical constants
    imu_convert.{c,h}    raw counts -> SI
    accel_cal.{c,h}      accel calibration
  control/
    drift.{c,h}          sinusoidal/square thrust modulation (drift_mod_t)
    pid.{c,h}            RPM PID
  safety/
    watchdog.{c,h}       dual-core spinlock watchdog
    rc_health.{c,h}      link-alive tracking
    battery.{c,h}        VBAT EMA + warn/halt thresholds
  imu/    imu_spi, latch     SPI + SN74HC595 chip-select latch
  dshot/  dshot + PIO        bidir DSHOT600
  crsf/   crsf               ELRS RC input

firmware/sim/
  plant.{c,h}            physics plant (rigid disc, arena)
  imu_synth.{c,h}        truth-state -> noisy/saturated measurement vector
  robot_sim.{c,h}        headless pure-angular kinematic sim
  drive.c                interactive raylib test-drive harness

firmware/tests/
  test_scenarios.c       closed-loop assert-based scenarios (wired to CTest;
                         there is no sim/scenario.c — it lives here)

firmware/sketches/         ESP32-C3 Arduino sketches (flashed separately)
  basestation/           RF beacon (ESP-NOW broadcast)
  esp-rssi/              robot RSSI receiver + heading pipeline -> UART to RP2350
```

**Key architectural rule:** the estimator + controller live in
`app/control_loop.c` and are called *identically* by the firmware (`main.c`,
split across two cores) and the sim. The sim never reimplements control logic;
it only supplies sensor readings and consumes motor throttles. This is what
makes the twin meaningful.

---

## 4. Estimation — as-built vs aspirational

**As-built (code today):** a reduced EKF with state `x = [theta, omega, alpha]`
(`meas_model.h`). Heading is dead-reckoned from `omega`; it is *not* directly
observable from body-frame accelerometers in steady spin (the fundamental
meltybrain observability limit). Measurement is a fixed 7-row set:

```
per IMU:  a_radial = omega^2 * r      (centripetal, outward +)
          a_tangential = alpha * r    (Euler term)
IMU-A only: gyro_z = omega
```

**Aspirational (braindump §11.3):** a 7-state angular-momentum filter
`[H_z, theta, omega, alpha, jerk, cor_x, cor_y]` with CoR estimation, jerk
augmentation, and eRPM fusion. Not yet implemented. Tracked as future work; the
twin is being built so the jump from 3-state to 7-state can be validated
against ground truth.

---

## 5. Anchored physical parameters (single source of truth)

Real numbers for this build. The sim `plant_params_t` defaults derive from
this table; change here and in the struct together.

| Parameter | Value | Notes |
|---|---|---|
| Mass | 0.454 kg | 1 lb antweight |
| Disc body radius `R_body` | 0.085 m | 170 mm body diameter (mass) |
| Weapon-tip radius `R_tip` | 0.115 m | 230 mm tip-to-tip; **collision radius** |
| Moment of inertia `I` | `k·m·R_body²`, k≈0.55 → ~1.8e-3 kg·m² | k tunable (mass distribution) |
| Thrust lever `r_w` | ~0.055–0.06 m | effective drive-wheel lever from centre |
| Normal RPM | 2600–2750 rpm (272–288 rad/s) | tracking mode, ~0.44 throttle |
| Strike/burst RPM | 3750–4000 rpm (393–419 rad/s) | pre-attack punch, ~0.65 throttle |
| Full-throttle terminal ω | ~644 rad/s (~6150 rpm) | headroom above combat RPM so drift modulation doesn't clip |
| Battery | 2S 350 mAh | |
| Arena | ~1.8 m square (5.9 ft), ¼" polycarbonate walls | half-extent 0.9 m; matches braindump ~6 ft antweight arena |

### IMU array

| IMU | Part | Radius | Angle | Gyro |
|---|---|---|---|---|
| A (inner) | LSM6DSV320X | 12 mm | 0° | yes |
| B (outer) | H3LIS331DL | 18 mm | 90° | no |
| C (outer) | H3LIS331DL | 18 mm | 210° | no |

### Sensor characteristics (from datasheets)

| Channel | Range | Quant (LSB) | Noise σ (est.) | Rails at |
|---|---|---|---|---|
| LSM6 hi-g accel | ±320 g | 9.77 mg = 0.096 m/s² | ~0.25–0.5 m/s² | 313 g |
| H3LIS accel | ±400 g | 195 mg = **1.91 m/s²** | **~2.5 m/s²** | 392 g |
| LSM6 gyro | ±4000 dps | 140 mdps = 0.0024 rad/s | ~0.001 rad/s | **69.8 rad/s** |

ODR / bus: H3LIS ≤ 1 kHz, LPF cutoffs 37/74/292/780 Hz, **no FIFO, INT
unconnected → must poll**. LSM6 ≤ 7.68 kHz. Shared SPI ≤ 10 MHz, one CS at a
time.

### Centripetal load at the sensors (a = ω²·r)

| Sensor | r | normal (2700 rpm) | burst (4000 rpm) | headroom |
|---|---|---|---|---|
| LSM6 inner | 12 mm | 98 g | 215 g | fits ±320 g |
| H3LIS outer | 18 mm | 147 g | 322 g | fits ±400 g (0.98·400=392) |

The mounting radii are chosen so the **accelerometers never rail during normal
play** — saturation only bites on impact spikes or overspin.

---

## 6. Twin findings (why the sim is being rebuilt)

1. **The gyro is pinned to its rail during every combat spin.** Spin is
   272–419 rad/s; the LSM6 gyro saturates at 69.8 rad/s (±4000 dps). Above
   ~670 rpm the gyro is railed by 4–6×. The old sim modeled the gyro as *never*
   saturating, feeding the EKF a perfect gyro that will not exist on hardware.
   Reality: `omega` comes from the accel centripetal channel at speed; the gyro
   only lives during spin-up start and shutdown, and as an impact anchor.
2. **The two accel families are very different.** Outer H3LIS are ~6–8× noisier
   and quantize in ~2 m/s² steps; the inner LSM6 is clean. The EKF's R matrix
   (and the sim's per-channel noise) should reflect that, not use one flat σ.
3. **ODR mismatch.** Outer sensors sample-and-hold at ≤1 kHz through a 292–780 Hz
   LPF with no FIFO (polled), giving ~15–22 samples/rev at speed and smearing
   transients. The inner sensor runs much faster.
4. **Wall rebound was black-box.** The old plant used Box2D's generic contact
   solver at RPMs and per-step rotations it was never designed for, with
   untuned restitution and no explicit spin↔translation coupling.
5. **Uncorrected H3LIS nonlinearity loses heading within ~3 s at combat RPM.**
   With the realistic sensor model, the ~5% full-scale droop biases omega
   enough that heading walks a full 180° in 3 s (2700 rpm). Noise alone
   (nonlinearity removed) gives ~13° drift at 2700 rpm, ~54° at 4500 rpm over
   the same window. So `accel_cal` is not optional — the nonlinearity curve is
   the single biggest determinant of heading hold. Wired: the sim rails the
   gyro at ±4000 dps and `meas_saturation_flags` now drops a railed gyro
   (inflates R), so the EKF leans on the accel centripetal channel at speed
   exactly as the hardware must; steady-state tests spin up from rest so the
   gyro can bootstrap omega's sign below 670 rpm before it rails.

---

## 7. SITL simulator

### 7.1 Architecture

The sim composes the **real** `app_` estimator/controller with a physics plant
and a synthetic IMU. Two front-ends share one plant + one sensor model:

- `robot_sim.c` — headless pure-angular kinematics (deterministic filter tests).
- `drive.c` — interactive raylib top-down view (hand-driving, watch heading lock).
- `tests/test_scenarios.c` — scripted assert-based regression scenarios → CTest.

### 7.2 Decision: hand-rolled plant (Box2D dropped)

The disc is a circle whose Box2D orientation is deliberately ignored (heading is
`∫omega`), so Box2D earned little and fought us at high RPM. The rebuilt plant is
a hand-rolled 2D rigid body: state `{x, y, vx, vy, theta, omega}`, semi-implicit
integration, heading integrated trapezoidally to match the EKF's midpoint
predict. Analytic circle-vs-square collision. Fully deterministic; removes the
high-RPM solver artifacts. Tradeoff: no free broad-phase if opponents/obstacles
are added later (revisit then).

All plant constants move into a `plant_params_t` struct so tuning lives in one
place and the harness can sweep it.

### 7.3 Wall contact model (the headline fix)

The disc **body** (radius 85 mm) gets a continuous circle contact: normal
bounce (restitution `e`), tangential **skitter** from rim friction, and **spin
bleed**, all from one friction-cone impulse.

On top of that, the two **weapon tabs** reach out to the 115 mm tip radius and
are modelled as point contacts. A fast-spinning tab striking a wall applies the
full rigid-body impulse (translation + rotation coupled through the lever arm),
so the robot is thrown off the wall and bleeds spin. Consequence: a **spinning**
bot driven into a wall gets flung clear (tabs bite, then it skitters away),
while a **dead** bot just pins and rests — it can't sit against the wall while
the weapon is live, matching the real robot. (A perfectly balanced bot placed
exactly grazing at rest is the one idealized case that still sits; real driving
never lands there.)

Defaults: `e_wall=0.35`, `μ_wall=0.5`, 2 tabs 180° apart.

### 7.4 Motor + drivetrain model

- Torque-speed curve per drive wheel: `τ = throttle·τ_stall·(1 − ω·r_w/v_free)`
  (back-EMF rolloff), so terminal RPM is set by the motor, not by fudged drag.
- **Full-throttle terminal ~6150 rpm**, deliberately well above combat speed.
  Combat RPM is reached at partial throttle (~0.44 for 2700, ~0.65 for 4000),
  which leaves headroom for the drift modulation. Setting the terminal at
  4000 rpm (the earlier mistake) meant combat RPM needed ~full throttle, so the
  modulation clipped and translation collapsed above ~3000 rpm. With headroom,
  translation is strong and roughly flat across 1000–4000 rpm.
- First-order **ESC lag** on commanded → applied throttle; spin-up time
  constant ~0.7 s (~1 s to 3000 rpm).
- Floor friction is **Coulomb** (`μ·m·g`), not linear viscous — this is why the
  arrow-key response feels less springy than the old Box2D build, and is the
  more realistic behaviour.

**Validated (§7.2–7.4, host smoke test):**

| Metric | Result | Target |
|---|---|---|
| Full-throttle terminal | 4001 rpm | ~4000 |
| Time to 3000 rpm | 0.99 s | < 2 s |
| 0.67-throttle terminal | 2681 rpm | ~2700 |
| Back-EMF spindown to 5% | 2.12 s | (free, no brake) |
| Heading-synced drift, A=0.30, 2 s | 1.08 m | > 0 |

Two emergent (correct) behaviours the twin now reproduces for free:

- **Constant asymmetric throttle produces zero translation** — a melty only
  drifts when the asymmetry is modulated in sync with heading. The plant
  enforces this; you cannot cheat drift open-loop.
- **ESC lag phase-shifts the drift direction** (~40° at cruise from
  `atan(2π·f_rev·τ_esc)`), so commanded `phi` maps 1:1 to world direction with
  a constant offset. This is exactly the `drift_phase`/`heading_trim` constant
  the firmware calibrates on the bench. `τ_esc` must stay well below the
  revolution period or the modulation is filtered out (why authority falls at
  very high RPM, matching community reports).

### 7.5 Sensor realism (`imu_synth`, datasheet-anchored)

- **Gyro saturation at ±4000 dps** (new shared `GYRO_FULL_SCALE`). The EKF
  finally faces a railed gyro during spin.
- **Gyro bias + in-run random walk** — the heading killer; stresses the filter.
- **Per-sensor accel noise + quantization** (outer ≈2.5 m/s² + 1.91 LSB, inner
  ≈0.3 m/s² + 0.096 LSB) instead of one flat σ.
- **Accel scale-factor / misalignment / zero-g offset** + mounting radius/angle
  perturbation vs nominal, so `accel_cal` has something real to solve.
- **Spin-synchronous vibration** (once-per-rev + harmonics) on top of white noise.
- **Per-sensor ODR sample-and-hold** (H3LIS 1 kHz + LPF, LSM6 fast) + optional
  dropped-sample for the pollable, FIFO-less outer chips.
- Everything behind flags with a seeded PRNG so tests stay deterministic.

The interactive `drive` tool uses a **calibrated** sensor (nonlinearity off),
because the real robot removes it with `accel_cal` and the SITL SI path doesn't
run that correction. Left on, the uncorrected bias walks heading and noticeably
worse while translating (the drift modulation ripples omega, so the
amplitude-dependent bias no longer trims out).

### 7.6 Scenario harness

`tests/test_scenarios.c` composes the plant + the real `app_` estimator and
controller, runs headless, and asserts on emergent behaviour. Wired into CTest
(`test_scenarios`), deterministic (seeded). Current scenarios, all passing:

1. **Spin-up** — full throttle reaches 3700–4100 rpm, EKF omega tracks within
   5%, and the gyro is confirmed pinned at its rail.
2. **Cruise drift** — commanding a stick direction at ~2700 rpm translates the
   robot (>0.1 m) while omega stays locked within 3% (calibrated sensor).
3. **Wall skitter** — a spinning disc coasted into a wall bounces (v_n reverses),
   skitters along it (tangential velocity appears from spin with motors off),
   and bleeds RPM.
4. **Nonlinearity matters** — uncorrected H3LIS nonlinearity walks heading far
   worse than the calibrated case; guards that `accel_cal` is mandatory.
5. **Burst saturation** — at overspeed the gyro and both outer H3LIS radials
   rail while the inner LSM6 accel stays in-spec (the mixed-radius payoff).

Deferred: per-sensor ODR sample-and-hold / dropped samples (H3LIS 1 kHz, no
FIFO) and `accel_cal` correction inside the SI estimation path.

### 7.7 Decisions in effect

- **Gyro-rail: expose-first.** The sim will model the real ±4000 dps rail even
  though it may stress/break the current EKF. That is the sim doing its job;
  any EKF changes are tracked as follow-up, not bundled into the sim work.
- **Starting tuning guesses:** `k=0.55`, `e_wall=0.35`, `μ_wall=0.5`, floor
  `μ≈0.4`. All one-line tunable in `plant_params_t`.
- **Build sequence:** plant → walls → motor → sensors → harness, testing each.

---

## 8. Open discrepancies / TODO

- [ ] EKF is 3-state as-built vs 7-state in braindump §11.3. Reconcile or
      re-scope the braindump when the augmented filter lands.
- [ ] Chassis geometry: braindump §4/§5 use 150 mm OD / 75 mm edge and are
      **out of date**. Current build: 170 mm body diameter (85 mm radius,
      carries mass), 230 mm tip-to-tip (115 mm weapon-tip collision radius).
      Refresh braindump G-load / tip-speed calcs to match.
- [x] Drift modulation mode is a **build-time flag** (`DRIFT_DEFAULT_MODE` in
      `control_loop.h`): flip the line or pass `-DDRIFT_DEFAULT_MODE=DRIFT_MOD_SQUARE`.
      No runtime toggle, by request.
- [x] `accel_cal` wired into the SI estimation path and validated end-to-end
      (loading the inverse curve recovers heading with nonlinearity on).
      Remaining: per-sensor curves (B and C share one today) and a bench
      routine to fill the table from a spin-up sweep.
- [x] Core 1 PID now uses the **measured** loop period, not the constant
      `CONTROL_DT` (that core also runs CRSF/DSHOT/telemetry, so the true
      period is longer). Matters when RPM PID is bench-tuned.
- [ ] Sim ODR fidelity: per-sensor sample-and-hold + dropped samples for the
      1 kHz, FIFO-less H3LIS outer accels (deferred from §7.5).
- [x] Box2D removed from `sim/CMakeLists.txt` and `flake.nix` (hand-rolled
      plant landed).

### Dead / unused code (flagged during code review)

These are compiled or defined but do nothing today. Each is either
scaffolding for a planned feature or leftover that should be pruned. Left
as-is they cost build size, reader confusion, and (for the `-Werror` host
build) latent warnings. Decide per item: **wire it or delete it.**

- **`latch_shadow` + `latch_get_image()` are dead.** `latch_load` caches the
  shadow byte but the only reader (`latch_get_image`, `static`) is never
  called, so the cache buys nothing. It exists for the braindump §11.2
  optimization (a single latch write that de-asserts the previous CS and
  asserts the next simultaneously), but `latch_select` instead does
  disable → load → enable every transaction, blanking outputs between reads.
  That is safe and simple; if we keep it, delete the unused shadow machinery.
- **`hardware_dma` + `hardware_irq` are linked but unused.** There is no DMA
  or IRQ code anywhere; core 0 captures IMUs with **blocking** SPI in a
  `busy_wait`-paced 1 kHz loop. Braindump §11.2's "DMA-driven burst reads →
  interrupt → process batch" is aspirational, not as-built. Drop the link
  deps until DMA lands, and note in the braindump that capture is currently
  polled.
- **CRSF `link_quality` / `rssi_dbm` are parsed but never read.** Arming uses
  only link-alive timeout + `rc_health` + battery. Fine to keep for future
  telemetry/LED use, but nothing consumes them yet.
- **eRPM telemetry is decoded but not fused.** `dshot_read_telemetry` runs and
  `rpm` is printed in the status line, but the EKF has no eRPM measurement row
  (consistent with the 3-state filter). This is expected today; listed so the
  gap is explicit when the 7-state / eRPM-fusion work starts.

### Firmware not yet started (braindump requires, no code exists)

Called out so the braindump's "firmware requirement" language isn't mistaken
for as-built:

- **Heading LED strobe** (braindump §11.3b). `PIN_HEAD_LED` is defined in
  `hw_pins.h` but nothing drives it. The mandated PIO hard pulse-width cap
  (fire-safety) is unimplemented.
- **SK9822 status LED + `LED_OE_N` gating** (braindump §11.2). `LATCH_BIT_LED_OE_N`
  is defined but never asserted; no LED frame is ever clocked.

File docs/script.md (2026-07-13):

### talking head intro

[outdoors] hi! I decided it would be a wonderful idea to design, manufacture, and assemble a combat robot to take to open sauce.

Sounds like a great idea! There is just one teeny tiny little problem with this plan though. It’s currently the 29th [show calendar] and I only have 20 days to design, manufacture, and build it before I have to be at opensauce. To make this even more exciting [strike out a week] I’m gone on a mission trip for 7 of those days.

### montage with narration

[montage] [research on chair] I had already been doing the research on combat robotics for the past week or so and had decided that I wanted to build a meltybrain. What is a meltybrain? [cut to orbitting early version of cad] Basically a spinning roomba of death with two steel spikes on the sides. [cut to project liftoff] Project Liftoff is one of the most famous meltys designed by the Kazmer family to compete in NHRL. Meltys tend to be incredibly robust and extremely deadly when driven correctly but their downside is extremely high stress on their electronics and complicated firmware.

### mathy part of the video

[cut to motion canvas] [beat 1: meltyspin up with arrow] Because meltys spin so fast they don’t have a constant forward direction. [beat 2: kick animation] In order to drift across the floor they have to “kick“ the motors at a specific point in each rotation to nudge it in a direction. Given a robot spinning at 3k rpm that is about 50 kicks a second which can give you some decent speed.

[beat 3: gyro redline] Most commerically available gyros aren’t able to handle such rotational speeds and cap out at a few thousand degrees per second at most or less than 4-500 rpm so we have to use accelerometers. [beat 4: accelerometer math scene] An acceleremeter is able to measure rotation by sensing the pull toward the outside of the bot. The faster you spin the bot the harder the pull is. If you have ever spun a ball on a string this is very similar. This acceleration [show a = ω² r] can be expressed as the spin rate squared times the distance from the center. We can flip the equation to solve for ω [show rearrange ω² =  a/r and then morph into ω = √(a / r)] and since we know the radius of the accelerometer and we know the acceleration we have solved for rotation rate. Unfortunately because rotation is quadratically related to acceleration it means that the g forces the accelerometer experiences grow drastically with increased rpm [rpm from 0 to 4500 mapped to g force reading at 20mm graph animate growing]. This means that at high speeds everything is perfect. We have extremely high signal and low noise but at lower speeds we have insanely high noise and next to no signal. 

[show integration graph of heading over time replacing bot spinning] Rotation rate is not quite what we need to precisely control the motors however. We need heading which can be integrated from rotation rate [show final equation theta = integrate(w dt) ideally animated in the same way as before]

[go back to spinng robot and start showing error; equations can clear] Because we integrate the rotation rate over time any little errors in our measurement also add up over time leading to heading drift. Now what i’ve been explaining so far is technically correct but a major simplification. The single accelerometer doesn’t just detect the pull toward the outside of the bot but it [show readout graph spiking widly] detects every bump in the floor, every hit, and every translation and can’t tell any of them apart. [add 3 acceleremeter dots with 2 at 18mm and 1 at 12mm at 0, 90, and 210 degrees] Now this is the fancy part of my bot. [show shove: show two line sensor read out with shove] If the robot gets shoved all 3 sensors feel that shove with the same magnitude but the spin pull varies by location. [animation subtraction between inner and outer sensor and show pure graph] If we subtract one sensor’s reading from another we can cancel out the shove. If we add a third sensor at another angle we can tell from which direction the shove came from.

Now because we have 6 measurements and 4 unknowns [show each gyro x and y measurement and a gap and then spin rate squared, angular acceleration, linear acceleration x and y] we can start to verify our work across sensors. We use a Kalman filter to predict where the robot should be next tick and then compare the sensor readings to that prediction.

[hide equations; show ekf approximation bell curves honing in on true answer] All of them will always be slightly wrong but they will usually be wrong in different ways. By weighting each measurement based on how much we trust the source at each moment we can fuse together our sources. The weight of each source becomes the width of a bell curve and then we can pick the highests point added between all of our curves to be our new prediction. We can even add extra sources like eRPM or (at lower speeds) a gyro to improve our accuracy. [ekf bell curves having finished multiple cycles hone in on final sensor measurement]

### Buillllllld

[scroll each datasheet] The PCB is designed around 3 accelerometers: 2 of the high-g H3LIS331DLTR from STM mounted at the outer radius and the inner LSM6DSV320XTR dual accelerometer / gyro also from STM. The MCU is an rp2350 on a xiao board chosen because of its PIO for DSHOT and also mostly just because I like working with RP chips and their ecosystem.

[cut to shot of kicad] The board is a 4 layer stackup with 2 outer signal layers and a power and ground inner layer. [power layer] The power layer is split into [highlight each with mouse] a VBUS, 5V, and 3V3 sections while the ground layer was kept completely clear to provide a clean groundplane for the traces above.

[go to schematic] The schematic is divided into a few subsheets. We have the power sheet with a selectable battery voltage cutoff level and the buck coverter. The IMU array sheet with the 3 accelerometers and their chip select shift register to help save on GPIO pins. Finally we have the status led sheet with our top and bottom RGB leds and our top and bottom heading leds.

[onshape assembly] Moving over to CAD we have the fully assembled bot here with the motors, wheels, pcb, and battery. I've used onshape for pretty much all of my cad projects (of which this was by far the biggest and taught me the most) and its great most of the time but I do wish it worked offline as it was a strugle to work on this in low internet environments.

[move to google sheets] My parts list is fairly long with most of the cost eaten by the PCB. Turns out double sided assembly and rush shipping are crazy expensive. The shipping is going to be crazy close and hopefully it will arrive in time for opensauce.

The only thing left to do now is build it!

### Assembly TBD

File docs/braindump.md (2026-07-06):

# Holy Guacamole — Full Project Braindump
 
**Robot:** Holy Guacamole — 1lb meltybrain antweight, MRCA full-combat ruleset  
**Document type:** Running knowledge dump — research, design decisions, hardware, firmware architecture  
**Target event:** Buckeye Bot Bash 2, Bellefontaine OH, Aug 29 2026  
**Status:** Pre-build, PCB spec complete, chassis design in progress
 
---
 
## Table of Contents
 
1. [What is a meltybrain](#1-what-is-a-meltybrain)
2. [Robot concept and goals](#2-robot-concept-and-goals)
3. [Ruleset constraints](#3-ruleset-constraints-mrca-full-antweight)
4. [Chassis design](#4-chassis-design)
5. [Operating parameters](#5-operating-parameters)
6. [Control theory research](#6-control-theory-research)
7. [Community RPM data and operating insights](#7-community-rpm-data-and-operating-insights)
8. [IMU placement — design evolution](#8-imu-placement--design-evolution)
9. [Electronics hardware](#9-electronics-hardware)
10. [Carrier PCB specification](#10-carrier-pcb-specification)
11. [Firmware architecture](#11-firmware-architecture)
12. [Mass budget](#12-mass-budget)
13. [Event calendar](#13-event-calendar)
14. [Reference builds](#14-reference-builds)
15. [Open questions](#15-open-questions)
---
 
## 1. What is a meltybrain
 
A meltybrain (also called translational drift) robot is a full-body spinner where the entire chassis rotates using its drive wheels as the weapon. Unlike a standard full-body spinner which uses a separate high-speed motor for the weapon, a meltybrain uses the drive motors themselves to spin the body. Directional control is achieved by modulating motor power at precise angular positions each revolution — effectively vectoring thrust by knowing exactly where the robot is pointing at any instant.
 
The key challenge: the robot has no static reference frame. It is spinning continuously at thousands of RPM. The control system must maintain a real-time estimate of chassis heading (0–360°) derived entirely from onboard sensors, and use that heading to decide which motor to power and when. Without accurate heading, the robot either cannot translate (no directionality) or worse, translates in the wrong direction.
 
This is fundamentally a state estimation problem wrapped around a control problem, not just a drive problem.
 
### Why it's interesting
 
A well-tuned meltybrain is simultaneously a full-body spinner (kinetic energy in the rotating mass) and a controlled mobile robot. The chassis IS the weapon. At 4,000 RPM and 75mm radius the tip speed is approximately 70 mph. Combined with metal weapon tabs, this is a meaningful combat machine.
 
The autonomous sensing extension (Holy Guacamole II) exploits the spinning geometry in a novel way: IR sensors spinning at 4,000 RPM scan the arena 67 times per second, building a polar reflectance map that can locate opponents without any external tracking infrastructure. This is impossible on a stationary robot and is one of the genuinely novel things this platform enables.
 
---
 
## 2. Robot concept and goals
 
**Name:** Holy Guacamole  
"Holy Guacamole" — chaotic energy, memorable pit presence.
"II" implies a lineage. Holy Guacamole II adds IR spinning lidar for autonomous opponent tracking.
 
**Design philosophy:**
- Holy Guacamole is a proof-of-platform. Manual RC control, validate the heading algorithm, prove the mechanical design survives combat.
- Holy Guacamole II upgrades the IMU fusion algorithm and adds spinning IR opponent detection.
- Keep the build achievable before the August 2026 deadline. Don't over-engineer Rev 1.
**Combat strategy:**
- Spin up to 4,000 RPM before engaging
- Translate toward opponent using drift control
- Weapon tabs at N/S, motors at E/W — weapon axis is perpendicular to drive axis
- Full invertibility — symmetric top/bottom design means being flipped is not a loss condition
---
 
## 3. Ruleset constraints (MRCA full antweight)
 
| Rule | Detail |
|---|---|
| Weight limit | 1.00 lb / 454g for wheeled robots |
| Materials | No restrictions — metal, UHMW, Delrin, carbon fiber all permitted |
| Active weapon | Meltybrain legality must be confirmed with each event organizer. MRCA ruleset lists "rolling (wheels, tracks, or the whole robot)" as permitted mobility and does not explicitly ban translational drift. **Confirm with Buckeye Bot Bash EO before committing to build.** |
| Spindown | Full stop within 60 seconds of power removal, self-contained braking. Active ESC braking satisfies this. |
| Failsafe | Radio must failsafe all motion (drive + weapon) on signal loss |
| Battery | LiPo permitted. Must be fully enclosed. Uncontained battery = automatic KO. |
| Arena | MDF floor, ¼" polycarbonate walls, ~6×6ft nominal |
| Match duration | 2 minutes |
| Pinning limit | 5 seconds max |
 
**Key note:** This is full-combat antweight, NOT plastic ant. Metal weapon tabs, UHMW chassis reinforcement, and carbon fiber are all permitted. Design accordingly.
 
---
 
## 4. Chassis design
 
### Form factor
 
Flat disc, 150mm OD, ~22mm max height at centre, flat puck profile. NOT lenticular/tapered — flat puck maximises wall count for structural strength and is trivially printable on a standard FDM printer.
 
### Weapon geometry
 
Two symmetric wedge tabs at 180° apart (N/S), protruding radially outward beyond the main disc radius in the horizontal plane only. Each tab has:
- Hard leading face approximately 90° to tangent — maximum impact energy transfer
- Smooth trailing taper back to disc radius over ~40° of arc — reduces drag and deflection
- Symmetric top/bottom for full invertibility
Metal tab inserts (Ti-6Al-4V titanium preferred, steel acceptable) bolted through from chassis body. Full-combat ruleset means no reason to use printed tabs.
 
### Print strategy
 
| Parameter | Value |
|---|---|
| Printer | Bambu A1 Mini (180×180mm bed, 0.4mm nozzle → 0.42mm extrusion width) |
| Material | Overture Super PLA+ — ductile failure mode, bends before breaking |
| Avoid | Duramic PLA+ — more brittle, worse for impact |
| Orientation | Flat on bed (disc face down) — layer lines horizontal, impacts load in tension/compression not delamination |
| Wall strategy | Maximum perimeters in multiples of 0.42mm. Wall count matters more than infill percentage. |
| Infill | ~80% gyroid |
| Seam placement | Away from battery pocket locations |
| Supports | None needed for flat disc geometry |
 
### Battery pockets
 
Two rectangular pockets at 180° (N/S), at ~55mm radius from centre. Batteries oriented with flat face tangential to rotation — centrifugal force compresses cell layers together, not apart. Pockets fully enclosed, batteries epoxy-potted in place. Must not eject under any loading condition.
 
### Motor mounting
 
Motors mount E/W (perpendicular to weapon tab axis N/S). This is a deliberate choice from Project Liftoff experience — motors at E/W prevent the robot from sliding sideways like a hockey puck when the weapon tabs face N/S. Drive axis perpendicular to weapon axis.
 
Hub motor architecture: the rotating motor bell/can is the wheel hub. Custom wheel hub attaches directly to the spinning can via 3× M2 holes on a 12mm bolt circle. Stator backplate bolts to chassis (fixed). This eliminates a dedicated axle and keeps mass close to the wheel.
 
One outboard R2ZZ bearing (1/8" ID × 3/8" OD) at each motor shaft tip, press-fit into a printed chassis arm extending to 75mm radius. Eliminates shaft flex from the ~45mm wheel overhang.
 
---
 
## 5. Operating parameters
 
| Parameter | Value |
|---|---|
| Target chassis RPM | 4,000 RPM (tunable 3,500–4,500) |
| Motor throttle at 4,000 RPM | ~65% — healthy thermal margin |
| Tip speed at 4,000 RPM, 75mm radius | ~70 mph |
| G at 12mm radius (inner IMU), 4,000 RPM | ~216G |
| G at 20mm radius (outer IMUs), 4,000 RPM | ~360G |
| G at 55mm radius (battery), 4,000 RPM | ~990G |
| G at 75mm radius (chassis edge), 4,000 RPM | ~1,350G |
| H3LIS331DL limit | ±400G hard ceiling |
| RPM ceiling (outer IMU at 20mm) | ~4,300 RPM before hitting 400G |
| Kinetic energy | ~400–600 mJ depending on final mass distribution |
 
**Why 4,000 RPM (revised upward from 1,800 RPM):**
- Motors run more efficiently at 65% throttle vs 30%
- Full-combat ruleset permits metal tabs — more damage at higher tip speed
- H3LIS331DL at 20mm radius has margin up to ~4,300 RPM before hitting G ceiling
- eRPM telemetry provides secondary RPM anchor independent of IMU
- Community data point: arithebiker runs D2822 1100KV at 4,200+ RPM successfully — validates motor choice empirically
**Two operational modes (community-validated "pounce" strategy):**
 
| Mode | RPM | Purpose |
|---|---|---|
| Tracking | ~3,000 RPM | Stable heading, good translation authority, follow opponent |
| Strike | ~4,000–4,300 RPM | Maximum KE, accept some heading degradation, burst engagement |
 
Community consensus (jbk9925, frugez, others): translation works best at 2,000–3,500 RPM. Above 3,500 RPM heading stability degrades with naive integrators. At 5,000+ RPM translation becomes unreliable. The EKF approach should extend the reliable translation window higher than OpenMelt-style integrators, but two-mode operation remains the right combat strategy.
 
Strike mode RPM ceiling: 4,300 RPM (outer IMU G limit). IMU-A (inner, 12mm) stays in-spec up to ~5,500 RPM — it becomes the primary sensor during high-RPM bursts when IMU-B/C approach their limit.
 
**Control loop rate requirement (community rule):**  
Minimum ~8 DSHOT updates per chassis revolution for translation. At 4,000 RPM (66.7 Hz): minimum 533Hz. At 4,300 RPM: 573Hz minimum. Our 1kHz loop rate on core 0 is comfortable at both operating points with ~15 update opportunities per revolution at 4,000 RPM.
 
---
 
## 6. Control theory research
 
This section documents the academic literature we identified as relevant to the heading estimation and control problem. The meltybrain community has largely not engaged with this literature — there is real opportunity here.
 
### 6.1 The core problem
 
At operating RPM, the robot's gyroscope channels saturate immediately (even high-range MEMS gyros max out well below 4,000 RPM = 24,000 °/s). Heading must therefore be derived from accelerometers only. The basic approach:
 
```
centrifugal acceleration = ω² × r
→ measure a_centrifugal from IMU
→ solve for ω
→ integrate ω over time → heading θ
```
 
This works at steady state but has several failure modes: spinup/spindown (low centrifugal signal), impacts (sudden ω change), and centre-of-rotation (CoR) shifts (mixes linear acceleration into the centrifugal reading).
 
### 6.2 Gyro-Free IMU literature (GF-IMU)
 
The formal name for "estimate angular velocity from accelerometers only" is gyroscope-free IMU or GF-IMU. This has been studied for ~30 years in aerospace and robotics. The combat robotics community has not engaged with it.
 
**Key paper: arXiv:2108.09834** — "Angular Velocity Estimation Using Non-Coplanar Accelerometer Array" (Maynard & Vikas, 2021)
 
Treats the problem as a dynamical system where accelerometer readings are simultaneously process and measurement inputs. Uses an EKF that discretises and linearises the continuous-discrete system. Key result: estimation noise scales inversely with the singular values of the relative displacement matrix between sensors. This gives a principled basis for sensor placement optimisation — not just "put them at 45°" but a formal criterion for what geometry minimises noise.
 
**Key paper: arXiv:1509.06494** — Cramér-Rao bound for accelerometer arrays
 
Establishes a fundamental limit: for purely gyroscope-free IMUs there is no unbiased finite-variance estimator for small angular velocities. Practically: your heading algorithm cannot work at very low RPM, and no amount of algorithmic sophistication changes this. There is a physical floor set by sensor noise and lever arm length. For Holy Guacamole this is fine — the centrifugal signal at 4,000 RPM at 20mm radius is ~360G, well above noise. The bound matters during spinup below ~500 RPM where the signal is marginal.
 
**GFSINS literature** (gyroscope-free strapdown inertial navigation systems)
 
Multiple accelerometers fused via Kalman filter, combining an "integral algorithm" with an "extraction algorithm." These papers work out the sign ambiguity problem formally — you cannot tell the sign of ω from a single accelerometer axis, which is exactly the zero-crossing problem. Project Liftoff's 45° dual-IMU placement solves this geometrically but without the formal underpinning. The GFSINS papers provide that underpinning and suggest more optimal geometries.
 
### 6.3 Spinning spacecraft attitude estimation
 
Spinning spacecraft are the closest physical analogue: object spinning fast, gyros saturated or unavailable, need heading from other sensors. This problem has been solved rigorously in aerospace.
 
**SpinKF (NASA Goddard, NTRS 20070032655)**
 
Uses a seven-parameter angular-momentum-based state representation rather than quaternions or Euler angles. Key insight: angular momentum varies more slowly than angle for a spinning body, making it a better state variable. Between attitude measurements, angular momentum is propagated using Euler's equations of motion. The state is `[H_inertial_x, H_inertial_y, H_inertial_z, H_body_x, H_body_y, H_body_z, rotation_angle]`.
 
**Application to Holy Guacamole:** parameterise the EKF state as angular momentum rather than angle. This makes the filter more robust during spinup/spindown transitions where angle changes rapidly but angular momentum changes slowly (only when motor torque is applied). Impact events appear as sudden angular momentum changes (impulsive torque), which is easier to model than sudden angle jumps.
 
### 6.4 Disturbance rejection
 
**VQF (arXiv:2203.17024)**
 
Achieves 2.9° average RMSE vs 5.3°–16.7° for existing methods. Key architectural idea: decouple the channels so disturbance in one measurement path doesn't corrupt the other. Applied to Holy Guacamole: decouple the eRPM-based ω estimate from the accelerometer-based heading integration. An impact that corrupts the accelerometers doesn't cascade into the eRPM channel, and vice versa. Each channel provides an independent ω estimate; the filter fuses them with appropriate confidence weights.
 
**Jerk-augmented EKF for impulsive disturbances**
 
Augmenting the EKF state with jerk (dα/dt, rate of change of angular acceleration) allows the filter to model and absorb sudden ω changes from impacts. A baseline EKF constrained to constant-acceleration assumptions overshoots dramatically during impact events. The jerk-augmented filter maintains physical consistency during the spike. Practical implementation: add one state variable (jerk), add one process noise term, update the state transition matrix. Modest complexity increase for significant robustness improvement.
 
### 6.5 Centre-of-rotation estimation
 
The CoR problem is specific to meltybrain and has not been published anywhere that we found. The issue:
 
On a two-wheeled meltybrain, the instantaneous centre of rotation during a drift manoeuvre is NOT the geometric centre of the disc. It shifts based on the differential thrust ratio between the two motors. Your IMU is mounted at a fixed position relative to the geometric centre, not the instantaneous CoR.
 
The centrifugal acceleration seen by an accelerometer at position **r** from the geometric centre is:
 
```
a = ω² × |r - r_cor| × r̂_from_cor
```
 
Where `r_cor` is the CoR offset from geometric centre. If your firmware assumes `r_cor = 0` (CoR at geometric centre) when it's actually offset, you get a systematic error in ω estimation that scales with drift authority.
 
At small drift inputs the error is second-order and negligible. At aggressive drift inputs (close to full differential thrust) the CoR can shift by several millimetres and the error becomes material.
 
**The three-IMU solution:** With three accelerometers at different angular positions, you have enough equations to solve for `{ω, α, a_linear_x, a_linear_y}` simultaneously. The linear acceleration terms (`a_linear`) directly encode the CoR offset — if they are nonzero, the CoR is displaced. Solving for them gives you a real-time CoR estimate that the heading algorithm can use as a correction. This is the primary motivation for the third IMU.
 
**The radially-separated solution:** One IMU at a different radius from the others allows differencing their radial readings to cancel linear acceleration (which is the same at all radii) and isolate the centrifugal term (which scales with radius). This was considered (inner IMU at 12mm, outer at 20mm) and incorporated into the final three-IMU design.
 
### 6.6 Summary of algorithmic innovations vs OpenMelt 2
 
| Feature | OpenMelt 2 | Holy Guacamole target |
|---|---|---|
| Heading integration | Naive integrator, open loop | EKF with angular momentum state |
| IMU count | 1 | 3 (asymmetric placement, mixed radii) |
| Zero-crossing handling | Single sensor, problematic | Geometric elimination via sensor layout |
| CoR compensation | None | Solved from 3-IMU over-determined system |
| Impact recovery | None (diverges) | Jerk-augmented state, eRPM re-anchor |
| RPM source | Accelerometer only | Accelerometer + eRPM fusion |
| Spinup heading | Lost | Tangential axis integration at low RPM |
| Steering | Square wave (on/off per 180°) | Sinusoidal thrust modulation |
 
---
 
## 7. Community RPM data and operating insights
 
This section captures empirical data from the meltybrain community (Discord, builder forums) that directly affects design and firmware decisions.
 
### 7.1 RPM operating ranges by weight class
 
| Weight | Typical RPM | Max seen | Notes |
|---|---|---|---|
| 150g | 2,000–3,000 | ~4,000 | Limited by motor size |
| 1lb ant | 2,000–4,500 | 4,500 | Sweet spot 3,000–4,000. arithebiker hits 4,200+ with D2822 1100KV |
| 3lb | 1,800–3,500 | ~5,000 | More mass = harder to spin up. Project Liftoff targets ~4k |
| Beetle | 2,000–6,000 | 8,000 | jbk9925's Shadow theoretical 7k, translates at 3–5k |
 
### 7.2 Translation RPM window
 
Translation works best at 2,000–3,500 RPM. Multiple builders confirm independently:
- jbk9925: "I translate around 3k. 5k is very unstable heading"
- frugez: "translation doesn't work well above 3k rpm for some reason"
- remzakmij: above 6,000 RPM, ESC response window too short for translation pulses
- zenith_parsec: achieved translation at ~300 RPM with low-range accelerometer and good filtering
Above ~3,500 RPM naive integrators lose heading lock (visible as heading indicator becoming a full circle rather than a point). This is not a fundamental limit — it's an integrator quality limit. The EKF approach targets maintaining heading lock through the 4,000+ RPM range where naive integrators fail.
 
**Minimum viable RPM for translation:** ~300–800 RPM depending on sensor quality. At 300 RPM, 20mm radius: 2.6G centrifugal — below noise floor for H3LIS331DL at 400G range. The tangential-axis spinup strategy (using α×r signal) handles this regime.
 
### 7.3 The pounce strategy
 
jbk9925's proven two-mode strategy: follow at ~3,000 RPM with stable heading, then punch to 4,500–5,000 RPM on engagement for maximum kinetic energy. This is now a first-class firmware requirement for Holy Guacamole:
 
- **Tracking mode (~3,000 RPM):** stable heading lock, high translation authority, pursue opponent
- **Strike mode (~4,000–4,300 RPM):** maximum KE, degraded heading acceptable, burst engagement
Implement as momentary switch on transmitter — hold to punch to strike RPM, release to return to tracking. EKF must handle the transition: when RPM setpoint changes, temporarily inflate process noise on ω state so the filter doesn't fight the intended change.
 
### 7.4 Andrew's Rules of Translational Drift
 
From remzakmij (Project Liftoff), the formal drift equation:
 
```
Drift = (Accuracy Coefficient) × (Power) × (Wheel Path / Wheel Diameter)
```
 
**Accuracy Coefficient:** how precisely you track RPM and pulse motors at the right heading. The EKF directly improves this vs naive integrator.
 
**Power:** watts delivered to ground — combination of motor power, wheel traction, and ESC response speed. AM32 > BLHeli_S here due to better low-speed torque control.
 
**Melty Ratio = Wheel Path / Wheel Diameter:**
```
Wheel path = 2π × chassis_radius = 2π × 75mm = 471mm per revolution
Melty ratio at 20mm wheel = 471 / 20 = 23.6
Melty ratio at 25mm wheel = 471 / 25 = 18.8
```
 
Higher ratio = more motor rotations per chassis rotation = more DSHOT update opportunities per revolution = finer translation authority. This is a real argument for smaller wheels. At 1kHz loop rate and 4,000 RPM: ~15 update points per revolution regardless of wheel diameter — the ratio affects how much ground is covered per update, not the update frequency itself. Smaller wheels = finer positional authority per update.
 
**Wheel diameter decision:** err toward smaller once motors are in hand and clearance is confirmed.
 
### 7.5 Spinup time
 
tedster: "fast spin up is everything." Most 3lb melties reach full speed in 2–3 seconds with good traction per remzakmij's data. With D2822 1100KV on 2S and estimated inertia, spinup to 3,000 RPM should be under 2 seconds. Tracking mode RPM reached before opponent engages — important for match opening.
 
### 7.6 H3LIS331DL nonlinearity warning
 
remzakmij discovered through years of testing that apparent CoR distance changed nonlinearly with RPM due to sensor nonlinearity. He built piecewise linear calibration models to compensate. Plan for this: do not assume H3LIS331DL reads linearly across its 400G range. Characterise each sensor across the RPM range (500, 1000, 2000, 3000, 4000 RPM) during bench testing and store calibration curves as firmware constants. This is more important for IMU-B/C at 20mm (operating at 90% of full scale at 4,000 RPM) than IMU-A at 12mm (54% of full scale).
 
### 7.7 ESC response time limit
 
Above ~6,000 RPM, ESC response window per revolution becomes too short for reliable translation pulses (remzakmij). At 4,000–4,300 RPM we are well within the reliable window. This sets an upper bound if RPM is ever pushed higher in future revisions.
 
---
 
## 8. IMU placement — design evolution
 
### Generation 1: Handoff spec (dual 45°, same radius)
 
Two H3LIS331DL at r=20mm, 45° apart. Taken from Project Liftoff rev 7+ approach.
 
**Problem:** Both at the same radius means centrifugal signal has the same magnitude scaling at both sensors. You can separate directions (sensors point different ways) but cannot separate "ω changed" from "CoR shifted" by magnitude. Linear acceleration from CoR displacement looks identical to a centrifugal scale change.
 
### Generation 2: Radially separated (considered and rejected)
 
Two IMUs on the same radial line at different radii (e.g. 12mm and 30mm).
 
**Benefit:** Differencing the two sensors cancels linear acceleration, isolates ω²·Δr. Summing gives linear acceleration directly. Clean CoR estimation.
 
**Problem:** At 4,000 RPM, r=30mm gives ~540G — over the H3LIS331DL ±400G hard limit. Only viable at the old 1,800 RPM target. Rejected for current design.
 
### Generation 3: Three sensors, same radius, asymmetric angles (Option C baseline)
 
Three H3LIS331DL at r=20mm, angular positions 0°/90°/210°.
 
**Benefit:** 6 accelerometer axes total. Full in-plane observability — can solve for {ω, α, a_x, a_y} simultaneously. Asymmetric angular spacing (not 0°/120°/240°) eliminates 3-fold rotational symmetry which would create heading angles where two sensors give degenerate information.
 
**Why 0°/90°/210° specifically:** The 90° gap between sensors 1 and 2 makes their radial axes orthogonal — clean X/Y decomposition of linear acceleration. The 210° third sensor breaks the remaining symmetry. No heading angle has two sensors giving identical projections.
 
### Generation 4: Three sensors, mixed radii, asymmetric angles — hybrid parts (current design)
 
Three IMUs:
- IMU-A (U4): **LSM6DSV320X**, r=12mm, 0° — accel ±320G + gyro ±4,000 dps
- IMU-B (U5): **H3LIS331DL**, r=~18mm, 90° — accel ±400G
- IMU-C (U6): **H3LIS331DL**, r=~18mm, 210° — accel ±400G
**Why LSM6DSV320X at the inner position:** The gyro channel (±4,000 dps = ~38,200 RPM equivalent) does not saturate at any planned operating speed. At 12mm radius the accel ceiling is ~5,500 RPM — well clear. The gyro provides direct ω integration from rest, replacing the spinup dead zone feedforward model with real data, and adds a third independent ω source to the EKF alongside the accelerometer array and eRPM. The LSM6DSV320X would saturate its accelerometer around 3,990 RPM at 18mm radius — too marginal for the outer positions, which is why H3LIS331DL ±400G stays there.
 
**SPI compatibility:** Both H3LIS331DL and LSM6DSV320X support SPI modes 0 and 3. Run shared bus at mode 0 (CPOL=0, CPHA=0) — SCK idles low, preventing deselected H3LIS331DL from misinterpreting bus traffic as I2C when CS is high.
 
**G ceiling verification:**
 
| Sensor | Part | Radius | G at 4,000 RPM | G at 4,300 RPM | Margin |
|---|---|---|---|---|---|
| IMU-A | LSM6DSV320X | 12mm | ~215G (67%) | ~248G (78%) | ✓ comfortable |
| IMU-B | H3LIS331DL | ~18mm | ~322G (81%) | ~372G (93%) | ✓ within spec |
| IMU-C | H3LIS331DL | ~18mm | ~322G (81%) | ~372G (93%) | ✓ within spec |
 
**Axis orientation convention:** Each chip mounted with X axis pointing radially outward, Y axis pointing tangentially. This makes the measurement model clean: radial axis gives centrifugal + CoR linear, tangential axis gives αr + tangential linear. Verify against H3LIS331DL datasheet before PCB layout.
 
---
 
## 9. Electronics hardware
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

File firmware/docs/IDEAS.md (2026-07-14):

# Ideas

## Traction Control via eRPM Slip Detection

If we get bidirectional DShot eRPM working, we can implement traction control:

1. Calculate expected wheel RPM from bot angular velocity (omega) and known geometry (wheel radius, track width).
2. Compare expected wheel RPM to actual eRPM from each motor.
3. If a motor's eRPM exceeds expected (wheel spinning faster than the surface speed implies), it's slipping. Reduce that motor's throttle until eRPM converges with expected.

This would improve drift consistency on low-grip surfaces and prevent spin-out during aggressive drift corrections. Requires reliable bidirectional DShot telemetry at control loop rate.

Related: RSSI-as-rotation-sensor research (see chat history 2026-07-13). eRPM gives per-motor ground truth; RSSI gives whole-body rotation without IMUs. Both could complement the existing accelerometer+gyro EKF.
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

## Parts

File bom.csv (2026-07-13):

price | link | seller | purchased
$25.99 | Betafpv lava 450mah 2s lipo | amazon | yes
$7.99 | 580 pcs heatshrink assorted | amazon | yes
$8.88 | 16 awg silicon wire 20ft red & black | amazon | yes
$12.48 | 26 awg silicon wire 100ft assorted colors | amazon | yes
$4.01 | 100 pcs m3 heatset inserts | amazon | yes
$6.99 | 5 pcs xt30 pigtails | amazon | yes
$12.99 | 750 pcs M3 stainless steel screws assorted | amazon | yes
$18.96 | xiao rp2350 x3 | robotshop | yes
$8.99 | 3.5mm bullet connectors | amazon | yes
$2.70 | Orange 2-3s tinysled | tinysled | yes
$7.81 | Elmer's Rubber Cement | amazon | yes
$12.95 | Liquid Latex | amazon | yes
$11.45 | ASI 388 Clear Electronic Grade Silicone 2.8oz | amazon | yes
$19.99 | High Density EVA foam block | amazon | yes
$45.00 | AM32 Dual Brushless Drive ESC | repeat robotics | yes
$29.98 | 2 pcs brushless outrunner 1100kv | palm beach bots | yes
$8.89 | Mini power switch 40a | palm beach bots | yes
$1.50 | Power Distribution Board | palm beach bots | yes
$8.99 | ELRS Lite Receiver | betafpv | yes
$9.74 | Toothies AR550 steel | sendcutsend | yes
$141.80 | pcb | oshpark | yes
$73.51 | stencil + solder paste | oshstencils | yes
$481.59
extra parts (not in bom cost)
price | link | seller | purchased
$14.99 | 1kg Inland green PLA+ (not included in bom costs) | microcenter | yes
$549.00 | PCB (double sided assembly + quick shipping) (refunded) | jlc | refund
$25.98 | 2 pcs 20a esc blheli_s | palm beach bots | yes

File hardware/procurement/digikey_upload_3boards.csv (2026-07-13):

DigiKey Part Number | Quantity | Customer Reference | Manufacturer Part Number | Manufacturer | Description | Stock Snapshot
445-9112-1-ND | 25 | C1 C4 C5 C19 C20 | C2012X5R1E226M125AC | TDK | 22uF 25V X5R 0805 ceramic capacitor | Five per board after AP63300 redesign; three input and two output; quantity includes hand-assembly spares
399-14148-1-ND | 50 | C2 C3 C7 C8 C9 C10 C11 C12 C14 C15 | C0402C104K3RACTU | KEMET | 100nF 25V X7R 0402 ceramic capacitor | 30 required for three boards after C16/C17 DNP; quantity includes hand-assembly and future-population spares
490-10467-1-ND | 10 | C6 C13 | GRM185R60J106ME15D | Murata Electronics | 10uF 6.3V X5R 0603 ceramic capacitor | 12819 DigiKey-direct; cut tape MOQ 1; checked 2026-07-12 22:38 EDT
SMAJ15CABCT-ND | 5 | D2 | SMAJ15CA | Bourns | 15V bidirectional 400W TVS DO-214AC SMA | 206756 DigiKey-direct; cut tape MOQ 1; checked 2026-07-12 22:38 EDT
ESD5B5.0ST1GOSCT-ND | 10 | D3 D4 | ESD5B5.0ST1G | onsemi | Bidirectional 5V ESD diode SOD-523 | 484952 DigiKey-direct; cut tape MOQ 1; checked 2026-07-12 22:42 EDT; approved replacement for PESD5V0V1BB,115
785-1002-1-ND | 5 | Q1 | AO3402 | Alpha & Omega Semiconductor | 30V N-channel MOSFET SOT-23 | 73984 DigiKey-direct; cut tape MOQ 1; checked 2026-07-12 22:38 EDT
541-10.0KYCT-ND | 40 | R1 R4 R5 R11 R19 R20 R21 R24 R26 | CRCW040210K0FKEDHP | Vishay Dale | 10k ohm 1% 0402 resistor | 65583 DigiKey-direct; cut tape MOQ 1; checked 2026-07-12 22:38 EDT
541-4092-1-ND | 10 | R10 | CRCW040233K2FKEDC | Vishay Dale | 33.2k ohm 1% 0402 resistor | 330808 DigiKey-direct; cut tape MOQ 1; checked 2026-07-12 22:38 EDT
541-4009-1-ND | 20 | R6 R7 R8 R12 R13 | CRCW040233R0JNEDC | Vishay Dale | 33 ohm 5% 0402 resistor | 433103 DigiKey-direct; cut tape MOQ 1; checked 2026-07-12 22:38 EDT
CR0402-FX-1003GLFCT-ND | 20 | R14 R15 R17 R18 R22 | CR0402-FX-1003GLF | Bourns | 100k ohm 1% 0402 resistor | 960871 DigiKey-direct; cut tape MOQ 1; checked 2026-07-12 22:38 EDT
MCS0402-100-CFCT-ND | 10 | R16 | MCS04020C1000FE000 | Vishay | 100 ohm 1% 0402 resistor | 82739 DigiKey-direct; cut tape MOQ 1; checked 2026-07-12 22:38 EDT
541-47.0KLCT-ND | 10 | R23 | CRCW040247K0FKED | Vishay Dale | 47k ohm 1% 0402 resistor | 373508 DigiKey-direct; cut tape MOQ 1; checked 2026-07-12 22:38 EDT
RMCF0402FT75K0CT-ND | 10 | R25 | RMCF0402FT75K0 | Stackpole Electronics | 75k ohm 1% 0402 resistor | 407602 DigiKey-direct; cut tape MOQ 1; checked 2026-07-12 22:38 EDT
P120KLCT-ND | 10 | R9 | ERJ-2RKF1203X | Panasonic Industry | 120k ohm 1% 0402 resistor | 119079 DigiKey-direct; cut tape MOQ 1; checked 2026-07-12 22:38 EDT
296-23258-1-ND | 5 | U11 | SN74HC595PWR | Texas Instruments | 8-bit shift register TSSOP-16 | 162109 DigiKey-direct; cut tape MOQ 1; checked 2026-07-12 22:38 EDT
497-13903-1-ND | 8 | U5 U6 | H3LIS331DLTR | STMicroelectronics | High-g accelerometer LGA-16 3x3mm | 5954 DigiKey-direct; cut tape MOQ 1; checked 2026-07-12 22:38 EDT
296-4709-1-ND | 8 | U8 U9 | SN74AHCT1G125DCKR | Texas Instruments | AHCT buffer SC-70-5 | 22001 DigiKey-direct; cut tape MOQ 1; checked 2026-07-12 22:38 EDT
1597-102010550-ND | 4 | U1 | 102010550 | Seeed Technology | XIAO RP2350 module; headers supplied loose and not installed | 385 DigiKey-direct; each MOQ 1; checked 2026-07-12 22:38 EDT
SRP6060FA-5R6MCT-ND | 5 | L1 | SRP6060FA-5R6M | Bourns | 5.6uH shielded power inductor 6.4x6.6mm | User confirmed immediate availability; DigiKey Marketplace cut tape; verify promised delivery date in cart
541-CRCW0402158KFKTDCT-ND | 10 | R27 | CRCW0402158KFKTD | Vishay Dale | 158k ohm 1% 0402 AP63301 feedback resistor | 8761 DigiKey-direct reported; cut tape MOQ 1
541-4109-1-ND | 10 | R28 | CRCW040230K1FKED | Vishay Dale | 30.1k ohm 1% 0402 AP63301 feedback resistor | 4438 DigiKey-direct reported; cut tape MOQ 1
445-5364-1-ND | 10 | C18 | C1005C0G1H470G050BA | TDK | 47pF C0G 50V 2% 0402 AP63301 feed-forward capacitor | 173399 DigiKey-direct reported; cut tape MOQ 1

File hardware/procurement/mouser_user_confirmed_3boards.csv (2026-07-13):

Mouser Part Number | Quantity | Customer Reference | Manufacturer Part Number | Manufacturer | Description | Status
511-LSM6DSV320XTR | 5 | U4 | LSM6DSV320XTR | STMicroelectronics | 6-axis plus high-g IMU LGA-14 2.5x3mm | Exact part; user confirmed Mouser stock
621-AP63301WU-7 | 5 | U2 | AP63301WU-7 | Diodes Incorporated | 3.8-32V 3A adjustable forced-PWM synchronous buck TSOT26 | User-provided Mouser listing reported approximately 35000 in stock; cut tape MOQ 1; safe drop-in for the AP63300 redesign

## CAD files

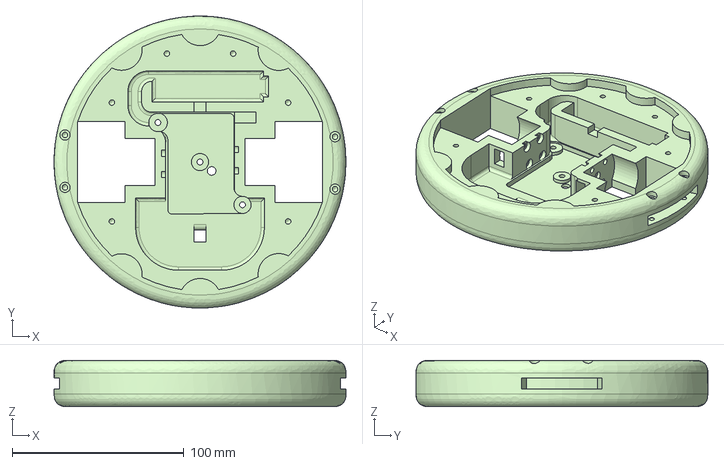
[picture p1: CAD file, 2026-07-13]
cad/body.step
170.0 x 169.9 x 27.0 mm

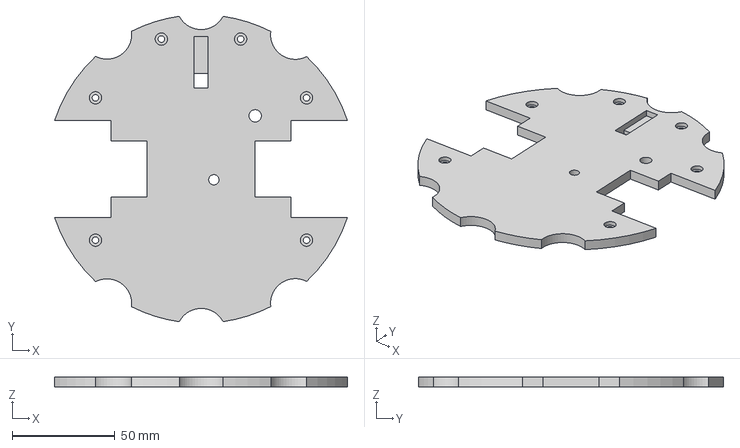
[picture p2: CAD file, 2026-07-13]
cad/lid.step
142.4 x 148.5 x 5.00 mm

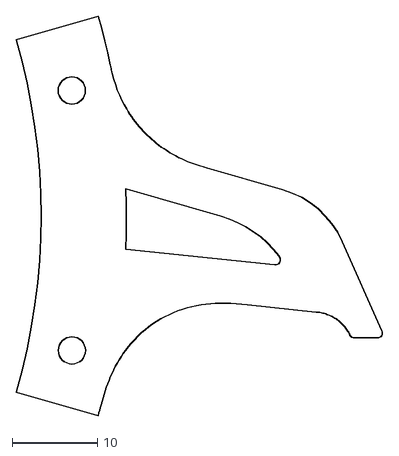
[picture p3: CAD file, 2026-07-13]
cad/toothie.dxf
43.0 x 46.9

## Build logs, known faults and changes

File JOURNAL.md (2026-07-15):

# The great journey of the one and only Holy Guacamole 🥑

**Running hour counter:** 93h

Okay this is a wee bit out of order bc I didn't start writing all of this down into after I realized I could do this for Outpost but from screenshots and git time stamps and my memory this is the best recontruction of the process up till now.

### Day numero uno: Saturday June 20th [5h15m]

I saw this [amazing video](https://www.youtube.com/watch?v=c7CI6yBTKMc) by Maker's Muse about a technique in orcaslicer to print stronger solid prints and then got fascinated by antweight combat robotics. I ended up going down a whole rabbit hole for the rest of the day. I discovered ring spinners pretty quickly (huge spinning blade around the outside) which seemed fascinating but a ton of work to build (some people have even made their [own motors](https://www.youtube.com/watch?v=scGufLuW8Do)). I also discovered that there was a competition ([Buckeye Bash](https://www.robotcombatevents.com/events/7385)) less then 45 minutes from me that was happening in August.

I was originally planning to do a plastic ant since it seemed quite cheap but as I started doing more research and looked at the rules for the competition it seemed more resonable just to do a full antweight robot. The [MCRA ruleset](https://docs.google.com/document/d/1A3H4qUD5gavUpnrbM_T5pSLp5FmKuVVwXHL0bRRfBec/edit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) is quite fascinating to read through and has such sections such as "10.4 Weapons with an open flame are not allowed. 10.4.2 Explosives or flammable solids such as: 10.4.2.2 Military Explosives, etc." which is absolutely hilarious and does make me wonder if anyone has tried to do that before.

One of the main things I was really curious about was something I could do a ton of software stuff with. I'm okayish at hardware but looooooove software and really wanted to design something that could leverage that. I remembered that the Hacksmith had done a bunch of work with autonymous operation at the large 30lb level but it mostly relied on computer vision outside the cage which seemed finicky and unreliable to me especially for smaller events where the cages are all different.

In the course of doing research about what the current software layout is I found out about meltys. Now meltys are conceptually very simple. You take the whole bot and you strap some metal blades to the outside and you have a hockey puck of death. Since you are able to rotate the entire robot directly and convert it into kinetic energy you are able use the whole robot. Thats 70% more robot in every shot! Cave Johnson aside its a pretty insane robot archtype that is also very uncommon. Hardware wise its very simple. Just add one or two motors and spin them opposite directions spinning your bot up to high rpms of about 2-4k. The hard part is the software. You essentially have to pulse the motors at very specific timings in the rotation in order to get it to translate across the floor. This is annoyingly hard to do because you need to know the rotation speed so you can also keep a heading lock. Most gyros cap out at much much lower rpms so most people end up going with an accelerometer. Even with an accelerometer though you have problems with g forces because at rpms like this you can easily experience 400-500 gs even just 3 cm from the center.

Now that I know I absolutely had to build a meltybrain I started looking at the hardware requirements. Keep in mind I didn't quite realize the IMU challenge quite yet and I was absolutely flying high on the front end of the Dunning-Kruger curve. I figured that a N20 gear motor would probably be fine right??? But then as I started doing more research I discovered it would not in fact be fine. The original opensource melty code [openmelt](https://github.com/nothinglabs/openmelt2/) used a big brushless motor and some of the newer ones like [potato melt](https://github.com/skysdottir/PotatoMelt) use brushless motors which means I need an esc :(

I knew I probably wanted to use an rp2350 for the board since they are just really nice to build with and their software stack is lovely. Finding an imu took ages especially since there are very few proper writeups about meltys on the public internet. But I basically stayed in this research hole getting more and more confused and rapidly feeling the complexity rise for the rest of the night. I went to bed at 23:45 that night having worked on this entirely since dinner at around 18:30ish.

### Day 2: June 21st [4h]

I started writing up a doc and a [google sheet](https://docs.google.com/spreadsheets/d/1paAJ0Wakvn5M726pM15FUGLVGKdC47_Wt41PN1yA9PQ/edit?gid=0#gid=0) of the things I was going to need for this and quickly realized it was going to be a ton of stuff. My goal from the start was to keep everything sub $250 though which did seem doable. I did some research and from what I could find PLA+ seemed to be a fairly well recommended choice for antweight bots in general and my local microcenter had some pretty green filament which looked nice.

I also ended up changing the name from Bogey One to Holy Guacamole once I saw the green filament as it kinda just fit perfectly. I also started looking for specific IMUs and nailed down the motors I wanted to get to the [Palm Beach Bots D2822](https://palmbeachbots.com/products/palm-beach-bots-d2822-brushless-outrunner-1100kv-0-125in-shaft) motors as they had a low enough kv that they could spin at a "low" rpm of 2-4k rpm. Finding a lower kv high torque motor was actually suprisingly hard especially since I was coming from the drone world so thats where I looked first and those are the exact opposite type of motor especially in this size range.

### Day 3: June 22nd [2.5h]

I finally made it to microcenter and bought the filament. I had to drag out my A1 mini from the closet and shockingly it still worked great! I printed a test cube and it was amazingly solid. It felt almost like an injection molded part which was crazy.

microcenter

I also was able to finalize where I wanted to buy my main parts from and find links for everything

google sheets

### Day 4: June 23rd [3h]

I started the cad and got an okayish looking round hockey puck thing but then wasn't entirely sure what to do next so I ended up emailing Palm Beach Bots and they actually had cad models for almost all of the parts I was planning on using! I started working on making holes for the motors to sit in and started also experimenting with parametric variables but I very much didn't know what I was doing and also got sucked down a rabbit hole of trying to reverse engineer the bambu lab network plugin (absolute hell btw) to get it to work with OrcaSlicer.

### Day 5: June 24th [5h]

I started fleshing out the pcb design! I realized that my inital ideas about how to do the gyro were a bit flawed and started reading a few research papers about using just accelerometers to measure rotation reliably. I ended up coming up with a really interesting approach that uses 3 accelerometers arranged in a triangle shape with one of them a bit closer to the center. This arrangement was inspired by a [paper](https://arxiv.org/abs/2108.09834
) on arxiv and theoretically should help be able to discriminate better between changes in different axis as well as elimentating deadzones. I settled on the [H3LIS331DL](https://www.st.com/resource/en/datasheet/h3lis331dl.pdf) from ST which is able to withstand up to 400gs and placed it at 20mm from the center which should keep it at about 350gs at max rpm.

I also realized I had a bit of a GPIO problem and needed an expander eventually settling on the [MCP23S17](https://ww1.microchip.com/downloads/aemDocuments/documents/APID/ProductDocuments/DataSheets/MCP23017-Data-Sheet-DS20001952.pdf) spi expander to help manage the CS pins on the accelerometers. I was able to get a fair bit of the schematic done before the day was done which I was fairly happy with.

### Day 6-8: June 25-27th - the amazing breakthrough [9h]

At this point I was kind of limping along with what i could glean from the internet and it was kind of a struggle to get more info on meltys. My friend Adam found out that I was looking to build a melty and invited me to the Hockey Pucks Of D̰͆͝E͕͆ͅA̤ͭ̂TͮͫH̞̃̎ discord server. This was the best thing that ever happened to this project. There are some absolutely incredible humans on there who have been working on meltys for the past 5 or more years and know so incredibly much. I started reading through as much of the discord as I could but there was just so much information available it was hard to stop lol.

the sad sad cad

I made a project channel in the discord and also started working on the cad a bit more. At this point its still in a pretty sorry state and I was still feeling very intimidated by onshape. It certainly didn't help that I was using my mac still so a touchpad for cad was miserable. I worked on the pcb a bunch more but that was about it for the day. I was able to get some motor cut outs working though and got into some interesting conversations about motors on the discord.

eod cad

I also did a bunch of research into wheels and found that foam wheels with a conformal coating and then silicone seem to be pretty highly recommended as having great traction and durability

### Day 9: June 28th [5h]

I actually got some good cad working!!!!!

good cad!!!

I had switched to my pcb at this point and ended up spending about 5 hours getting to this point and was feeling actually amazingly confident with onshape!

I also had gotten the schematic mostly to a place where I liked to and gotten it semi organized. At this point I asked for a design review in both slack and discord and got some great feedback!

schematic round 1

### Day 10: June 29th [4.5h]

nice schematic

The schematic being so messy really stinking bugged me so I spent far too long organizing it into hierarchical sheets and integrating the feedback I got on the first version. I also cleaned up a bunch of the messy wiring that just didn't look very nice.

I also printed the first iteration of the CAD at this point to see if it fit the newly arrived motors and esc. I printed it in crazy low infill but everything did mostly fit which was amazing for my confidence. At this point I also started considering outpost as something that might make sense for this project and that kicked my brain into high gear and I ended up spending another several hours refining the cad again and redesigned the way the top and bottom fit together and got screws all fancy and working.

printed model

### Day 11: June 30th [3.5h]

I spent a bit researching screw types which are more complicated then I realized and then ended up redoing to the cad again to switch to partially sunk machine screws instead of the fully countersunk screws I was attempting to put in the cad before.

fancy screws

I also spent a while double checking my BOM and making sure I had all the things I was going to need. Ended up staying up way too late thinking about melties and the ways I could optimize mine.

### Days 12 and 13: July 1st and 2nd [0h]

I did pretty much nothing these two days because I flew to NYC to spend 2 days onsite with [Charm](https://charm.land/). It was a ton of fun to meet everyone IRL and I got to visit the slack office in salesforce tower! I also was able to play with my new camera a bunch and took a bunch of great photos :)

photo of me and my host Ale in salesforce tower
some photos I took

### Day 14: June 3rd [8h]

[15:00ish] This brings me to the present where I'm writing this and just finished a final review of my schematic. It took actually a shockingly long time I write this all out (about 2 hours 😭) but it was really fun to recap and kind of insane to realize that this entire project came together in 2 weeks. I'm going on a mission trip tomorrow so I have to finish routing the pcb tonight and get it sent off for one final design review from a real EE (i'm so thankful for this) and then get it made at JLC! I'm really hoping that I can get everything made quickly enough bc outpost and opensauce are coming up wayyyy too quickly (18th and 19th for opensauce) and I have practically no time left.

[23:30] I stayed up far too late to get the pcb finished (skipped the review and will have them check the pcb hopefully quickly ish). I'm not really happy with the shape but I already had to reroute it several times so i'm not partiularly excited to do it again. I decided to see how good freerouting has gotten and its still miserable. I had to delete everything it produced as it skipped the simplest of traces. Who knows the mind of the autorouter :shrug:

image of the horrible first pass

I was able to discover a pretty good trick for designing the pcb though. If you export a top down view of the onshape model and then clean it up in an svg editor you can import it as a user drawing layer into kicad and then size your edgecuts relative to that. You do need to calibrate the scale via a reference line though.

### Day 15: June 4th (14 days to opensauce) [5h]

It's the 4th of July and i'm on the road. Started driving down to north carolina about 9 and ended up completely ripping out the entire pcb and redesigning the edgecuts so its a bit more compact. Originally started out with a 2 layer board but was having problems keeping the ground plane clean for the spi traces and was also having some problems reaching all of the components. I got inspired by someone in the melty discord to add these little protrusions off the side for screw holes.

After moving to a 4 layer design I decided on a signal-power-gnd-signal stackup splitting the power plane into 3 seconds for vbus, 3.3v, and 5v. Happily the components almost perfectly split across these lines so I only needed two traces on the powerplane. Also added a bunch of stiching vias to tie the gnd planes together and added a copper pour on the top and bottom of the board.

I'm really hoping that that i've covered everything here. I'm 90% sure I have and I've done a million reviews of the schematic and tripple checked everything. I just need to get the BOM for jlc ready which mostly just means picking caps and resisters and then get this producing. It's going to be a crazy tight turnaround as even with fast shipping JLC takes about 8 days to get to the US. I'm really hoping to have everything arrive in time.

| | |
|---|---|
| render 4 | render 3 |
| render 2 | render 1 |

### Day 16: June 5th [4h]

I added some stiching vias as mpk recommended on slack and got proper copper pours on top and bottom. Started working on getting all of the bom parts ready for JLC and discovered a bug with my original SPI idea where the H3LIS331DLTR used the CS pin to enable and disable SPI is slightly broken as for some (in my dumb opionion insane but probably perfectly reasonable) reason when CS is 0 it switches to I2C instead of SPI. If I use mode 0 SPI and add a 100k pulldown to gnd on spi sck i think it should be fine. The pcb is unfortunately scarrily expensive with shipping and assembly and came out to just over $350.

jlc quote

Also started working on the firmware and I got some good benchtest code ready and am working on the EKF fusing code. Ideally I can get a sim ready soon but that seems unlikely to get done this week (saying that i'll stay up till 4am tmrw and finish wont I :pf:).

### Day 17: June 6th [5h]

Well my prediction from yesterday was correct lol. I now have a simulator albiate a not crazy good one but it will improve. I need to do quite a lot of hardware in the loop testing before hand to iron out the bugs before I get the actual hardware. The lovely thing is that this is all pretty simple physics and so not terribly hard to model in software. I'm doing an end to end simulation running the exact same code as on the bot just with a simulation mock for the receiver, escs, and imus.

I also did a bunch of iteration on the blades as I wasn't super happy with the way that I got them initally. I tweaked them a ton but eventually had to go to sleep after messing up one of the sides and realizing I was far too tired to do good work.

the first blades

### Day 18: June 7th [5h]

I did a bunch more work on the firmware and now have full ekf working and the sim mostly behaving! I also received my design review from solderable's EE Tyler (thank you ^^) and discovered that I put my caps too far away from the buck covertor and the imu. Thankfully it wasn't a terrible fix but I also discovered a few other issues in the process. I got a quote back from pcbway as well and they are offering $280ish which is better than jlc's $360. The main downside is that pcbway moves a wee bit slower in my experience but the quality is usually really good.

I also redesigned the toothies (my offical name for them) to be wayyyy smaller and far more lightweight than last night. They should weight about 40g each now and hopefully be a bit stronger since they don't have massive parallograms in the middle anymore.

I stayed up far too late working on this yet again and now i'm typing this up as I wait to see if i heard back from pcbway quickly and can get my design into motion. I also probably need to add a low battery cutoff to the buck convertor but thats annoying and may have to wait depending on how long everything takes and how fast pcbway gets back.

### Day 19: June 8th [6h]

I have now offically purchased the pcb! I found out a pretty big issue with the pcb initally where it extended into the wheel wells which would have prevented the wheels from turning. I extended the pcb and that also opened up some silkscreen room which is amazing. I also made a copper heatsink for the esc and tweaked the assembly model a ton to get the pcb properly mounted.

I purchased the pcb and toothies which was immensely painful. JLC ended up being $524.56 which feels insane. Tarifs / Duties alone was $115 😭

Send Cut Send was amazingly quick and also nicely cheap. The toothies cost about $4 each which wasn't bad and the copper heatsink was $7ish. Shipping was double the cost of parts hilariously. I definely want to order stuff from them again. Unfortunately the estimated shipping arrival dates on both JLC and SCS is the 16-17th right before I have to leave. It's going to be scarily close. I'm going to work a ton on the simulator and hopefully also make the wheels and assemble pretty much everything else accept for the electronics. My main worry is that it is going to be too hard to add the strain relief connections since that is liquid latex which won't transfer well on the plane. If worst comes to worst I can just solder the connections after I get there and take a small bottle of latex. We shall see.

I'm also still shocked at how much time I keep etching out of the day for this. TBF I stayed up till 3am this morning and have been spending 2 hours before and after dinner each afternoon so it does really add up.

the pcb after extension

### Day 20: June 9th [15m]

Wasn't able to do much today just confirmed the replacement of my inductor bc I grabbed the wrong lcsc part # :facepalm: Thankfully JLC was nice about it and I could just replace the part with one that fit the correct footprint. Tried to do some onshape stuff and submit the outpost forms but slow internet made that extremely painful.

### Day 21: June 10th [3h]

Today was mostly spent in the car so i worked on the firmware and got it reflecting the real world sensors much more closely. The physics model in the sim is now much more accurate and rebounds work correctly. Also was able to fix several things with the accelerometer code that was manifesting in the sim! I'm hoping that the sim will help catch all / most of the bugs if possible but who knows. I'm really hoping that the wrong part # didn't delay JLC too too long.

### Day 22: June 11th [5h]

Today was mostly a ton of work on the explainer video in motion canvas. I got the video and script most of the way to where I wanted it and also started some editing in davinci after filming the intro sequences. Recorded the voiceovers and worked on the script for absolutely ages.

motion canvas

### Day 23: June 12th [10h]

Worked on finishing out the voiceovers for the first few hours and then finished editing the explainer bit of the video and started working on refining the last bits of the mounting cad. Was able to finish that and start printing the body of the bot after agonizing on how to cut down on weight in the slicer. I also was able to figure out a way to possibly get the pcb in time. I'm going to order the pcb from oshpark and get a stencil from oshcut and then assemble the parts myself. Hopefully it will be a tiny bit faster and everything should arrive in time.

### Day 24: June 13th [4h]

After waking up I had a bad feeling about the parts available so I double checked the availability and the LSM accelerometer and my buck convertor were out of stock as well as my inductor. I had already submitted the order to oshpark last night so I made a mad dash to get all the parts changed over and update the pcb. Thankfully oshpark is lovely and you can update your design files as long as it stays the same boundary size. I had a ton of issues with mouser just flat out not letting me check out but after letting it sit for a few hours it worked and I was able to get a new buck convertor and the accelerometer from them and the rest of the parts from digikey!

### Day 25: June 14th [6h]

Today was mostly just wheels wheels wheels. I worked on the hub design which went through at least 8 different prints. Turns out cutting eva foam is a nightmare but I eventually settled on just using a hole saw and then drilling out the center with the largest drill bit I had. I had a ton of trouble fitting my hubs on but eventually decided on a design that runs 3 m2 screw directly through the hubs into the motors which hopefully should be pretty strong. I need to coat the wheel tomorrow after my screws arrive.

I also did a bunch of looking into a concept for detecting rotation using the antenna deadzone on an esp32 from [Trevor](https://github.com/TGower/rotation_sensing). It's a brilliant idea that blast esp now packets at a esp on the bot and when the bot spins there is a drop in rssi right as it passes the antenna deadzone. You can fit a little PLL to it and you have rotation! It's a brilliant idea and one I definetly want to steel for my full bot and even more importantly in the case that my pcb doesn't arrive in time it would still let me drive my bot.

wheels in the hole saw

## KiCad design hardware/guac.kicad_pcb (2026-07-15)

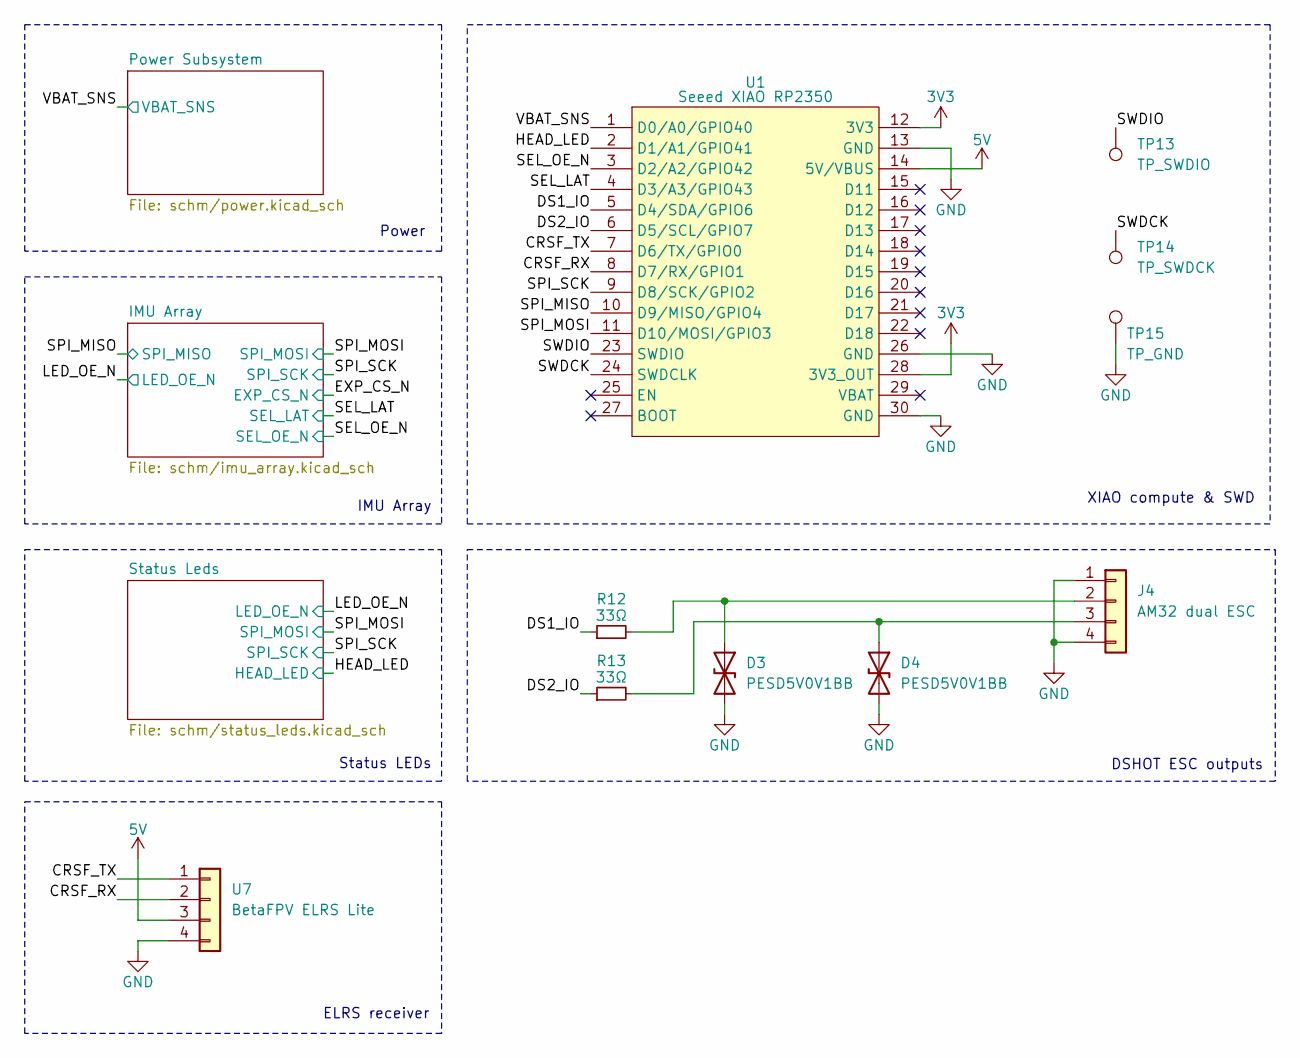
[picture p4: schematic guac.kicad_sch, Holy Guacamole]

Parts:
D3, D4: PESD5V0V1BB; D_SOD-523; LCSC Part C477993
J4: AM32 dual ESC; SolderWire-0.25sqmm_1x04_P4.2mm_D0.65mm_OD1.7mm; LCSC Part NONE
R12, R13: 33Ω; R_0402_1005Metric; LCSC Part C3008986
TP13: TP_SWDIO; TestPoint_Pad_D1.0mm; LCSC Part NONE
TP14: TP_SWDCK; TestPoint_Pad_D1.0mm; LCSC Part NONE
TP15: TP_GND; TestPoint_Pad_D1.0mm; LCSC Part NONE
U1: Seeed XIAO RP2350; XIAO-RP2350-SMD; LCSC Part NONE
U7: BetaFPV ELRS Lite; BetaFPV_ELRS_Lite; LCSC Part NONE

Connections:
3V3: U1.12 (3V3), U1.28 (3V3_OUT); also elsewhere on the board
5V: U1.14 (5V/VBUS), U7.3; also elsewhere on the board
/CRSF_RX: U1.8 (D7/RX/GPIO1), U7.2
/CRSF_TX: U1.7 (D6/TX/GPIO0), U7.1
/DS1_IO: R12.1, U1.5 (D4/SDA/GPIO6)
/DS2_IO: R13.1, U1.6 (D5/SCL/GPIO7)
/HEAD_LED: U1.2 (D1/A1/GPIO41); also elsewhere on the board
/SEL_LAT: U1.4 (D3/A3/GPIO43); also elsewhere on the board
/SEL_OE_N: U1.3 (D2/A2/GPIO42); also elsewhere on the board
/SPI_MISO: U1.10 (D9/MISO/GPIO4)
/SPI_MOSI: U1.11 (D10/MOSI/GPIO3); also elsewhere on the board
/SPI_SCK: U1.9 (D8/SCK/GPIO2); also elsewhere on the board
/SWDCK: TP14.1 (1_1), U1.24 (SWDCLK)
/SWDIO: TP13.1 (1_1), U1.23 (SWDIO)
/VBAT_SNS: U1.1 (D0/A0/GPIO40); also elsewhere on the board
GND: D3.2 (A2), D4.2 (A2), J4.1, J4.4, TP15.1 (1_1), U1.13 (GND), U1.26 (GND), U1.30 (GND), U7.4; also elsewhere on the board
unnamed: D3.1 (A1), J4.2, R12.2
unnamed: D4.1 (A1), J4.3, R13.2

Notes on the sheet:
ELRS receiver
Status LEDs
IMU Array
DSHOT ESC outputs
XIAO compute & SWD
Power

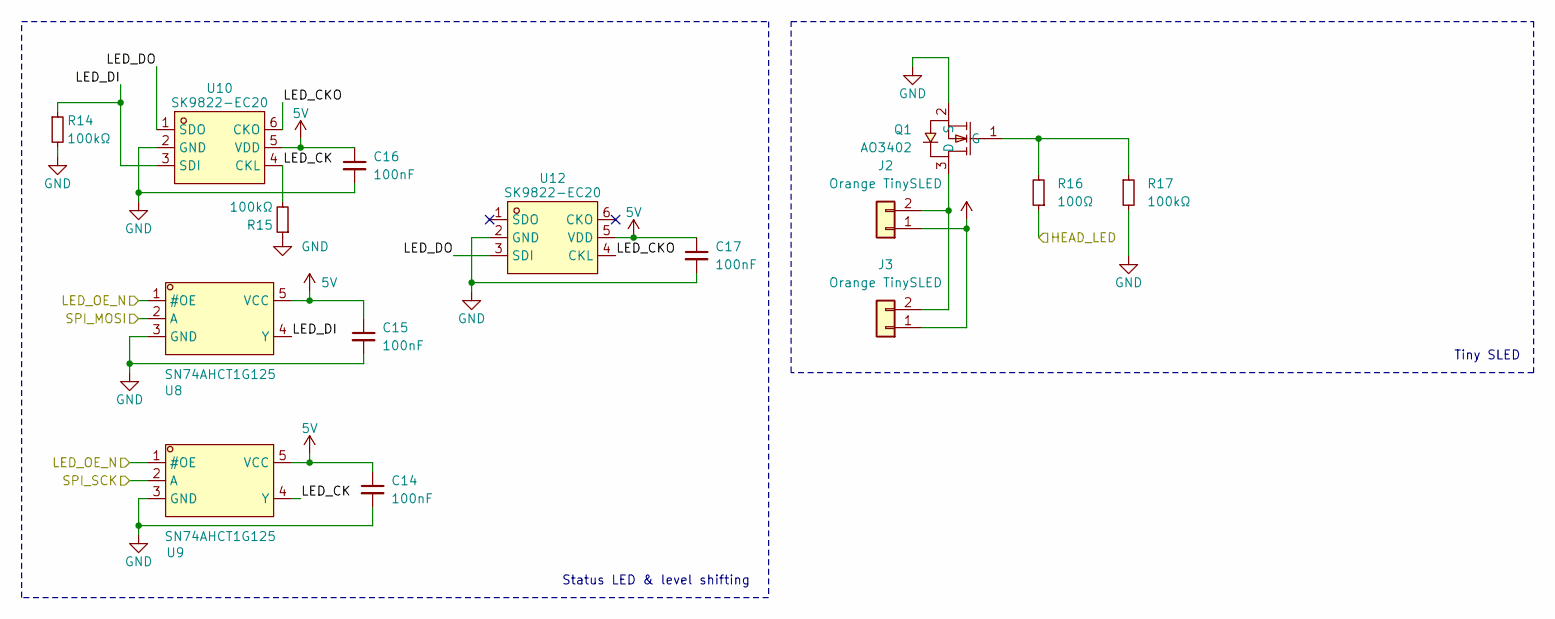
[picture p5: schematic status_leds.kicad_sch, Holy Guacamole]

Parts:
C14, C15, C16, C17: 100nF; C_0402_1005Metric; LCSC Part C169834
J2, J3: Orange TinySLED; SolderWire-0.25sqmm_1x02_P4.2mm_D0.65mm_OD1.7mm; LCSC Part NONE
Q1: AO3402; SOT-23_L2.9-W1.3-P1.90-LS2.4-BR; LCSC Part C14385
R14, R15, R17: 100kΩ; R_0402_1005Metric; LCSC Part C2077080
R16: 100Ω; R_0402_1005Metric; LCSC Part C1884631
U8, U9: SN74AHCT1G125; SC-70-5_L2.0-W1.3-P0.65-LS2.1-BL; LCSC Part C350557
U10, U12: SK9822-EC20; LED-SMD_6P-L2.0-W2.0-P0.80-TL; LCSC Part C2909059

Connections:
5V: C14.1, C15.1, C16.1, C17.1, U8.5 (VCC), U9.5 (VCC), U10.5 (VDD), U12.5 (VDD); also elsewhere on the board
/HEAD_LED: R16.1; also elsewhere on the board
/LED_OE_N: U8.1 (#OE), U9.1 (#OE); also elsewhere on the board
/SPI_MOSI: U8.2 (A); also elsewhere on the board
/SPI_SCK: U9.2 (A); also elsewhere on the board
/Status Leds/LED_CK: R15.2, U9.4 (Y), U10.4 (CKL)
/Status Leds/LED_CKO: U10.6 (CKO), U12.4 (CKL)
/Status Leds/LED_DI: R14.1, U8.4 (Y), U10.3 (SDI)
/Status Leds/LED_DO: U10.1 (SDO), U12.3 (SDI)
GND: C14.2, C15.2, C16.2, C17.2, Q1.2 (S), R14.2, R15.1, R17.2, U8.3 (GND), U9.3 (GND), U10.2 (GND), U12.2 (GND); also elsewhere on the board
unnamed: J2.2, J3.2, Q1.3 (D)
unnamed: Q1.1 (G), R16.2, R17.1
VBUS: J2.1, J3.1; also elsewhere on the board

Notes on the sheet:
Tiny SLED
Status LED & level shifting

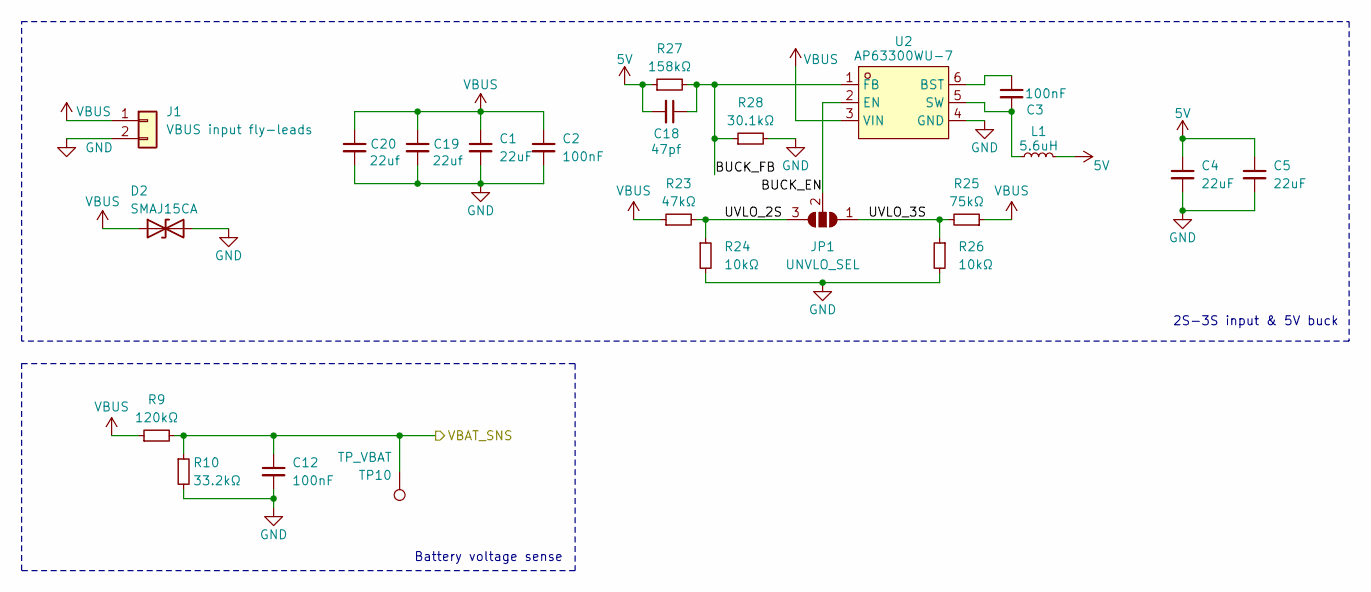
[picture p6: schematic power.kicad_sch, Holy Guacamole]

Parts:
C1, C4, C5: 22uF; C_0805_2012Metric; LCSC Part C602037
C2, C3, C12: 100nF; C_0402_1005Metric; LCSC Part C169834
C18: 47pf; C_0402_1005Metric
C19, C20: 22uf; C_0805_2012Metric
D2: SMAJ15CA; D_SMA; LCSC Part C110044
J1: VBUS input fly-leads; SolderWire-0.25sqmm_1x02_P4.2mm_D0.65mm_OD1.7mm; LCSC Part NONE
JP1: UNVLO_SEL; SolderJumper-3_P1.3mm_Open_Pad1.0x1.5mm
L1: 5.6uH; L_Bourns_SRP6060FA; LCSC Part Bourns SRP6060FA-5R6M
R9: 120kΩ; R_0402_1005Metric; LCSC Part C409883
R10: 33.2kΩ; R_0402_1005Metric; LCSC Part C3008937
R23: 47kΩ; R_0402_1005Metric; LCSC Part C482184
R24, R26: 10kΩ; R_0402_1005Metric; LCSC Part C844715
R25: 75kΩ; R_0402_1005Metric; LCSC Part C237746
R27: 158kΩ; R_0402_1005Metric
R28: 30.1kΩ; R_0402_1005Metric
TP10: TP_VBAT; TestPoint_Pad_D1.0mm; LCSC Part NONE
U2: AP63300WU-7; TSOT-23-6_L2.9-W1.6-P0.95-LS2.8-BL; LCSC Part AP63300WU-7

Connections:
5V: C4.1, C5.1, C18.2, L1.2, R27.1; also elsewhere on the board
/Power Subsystem/BUCK_EN: JP1.2 (C), U2.2 (EN)
/Power Subsystem/BUCK_FB: C18.1, R27.2, R28.1, U2.1 (FB)
/Power Subsystem/UVLO_2S: JP1.3 (B), R23.2, R24.1
/Power Subsystem/UVLO_3S: JP1.1 (A), R25.2, R26.1
/VBAT_SNS: C12.1, R9.2, R10.1, TP10.1 (1_1); also elsewhere on the board
GND: C1.2, C2.2, C4.2, C5.2, C12.2, C19.2, C20.2, D2.2 (A2), J1.2, R10.2, R24.2, R26.2, R28.2, U2.4 (GND); also elsewhere on the board
unnamed: C3.1, U2.6 (BST)
unnamed: C3.2, L1.1, U2.5 (SW)
VBUS: C1.1, C2.1, C19.1, C20.1, D2.1 (A1), J1.1, R9.1, R23.1, R25.1, U2.3 (VIN); also elsewhere on the board

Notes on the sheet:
Battery voltage sense
2S-3S input & 5V buck

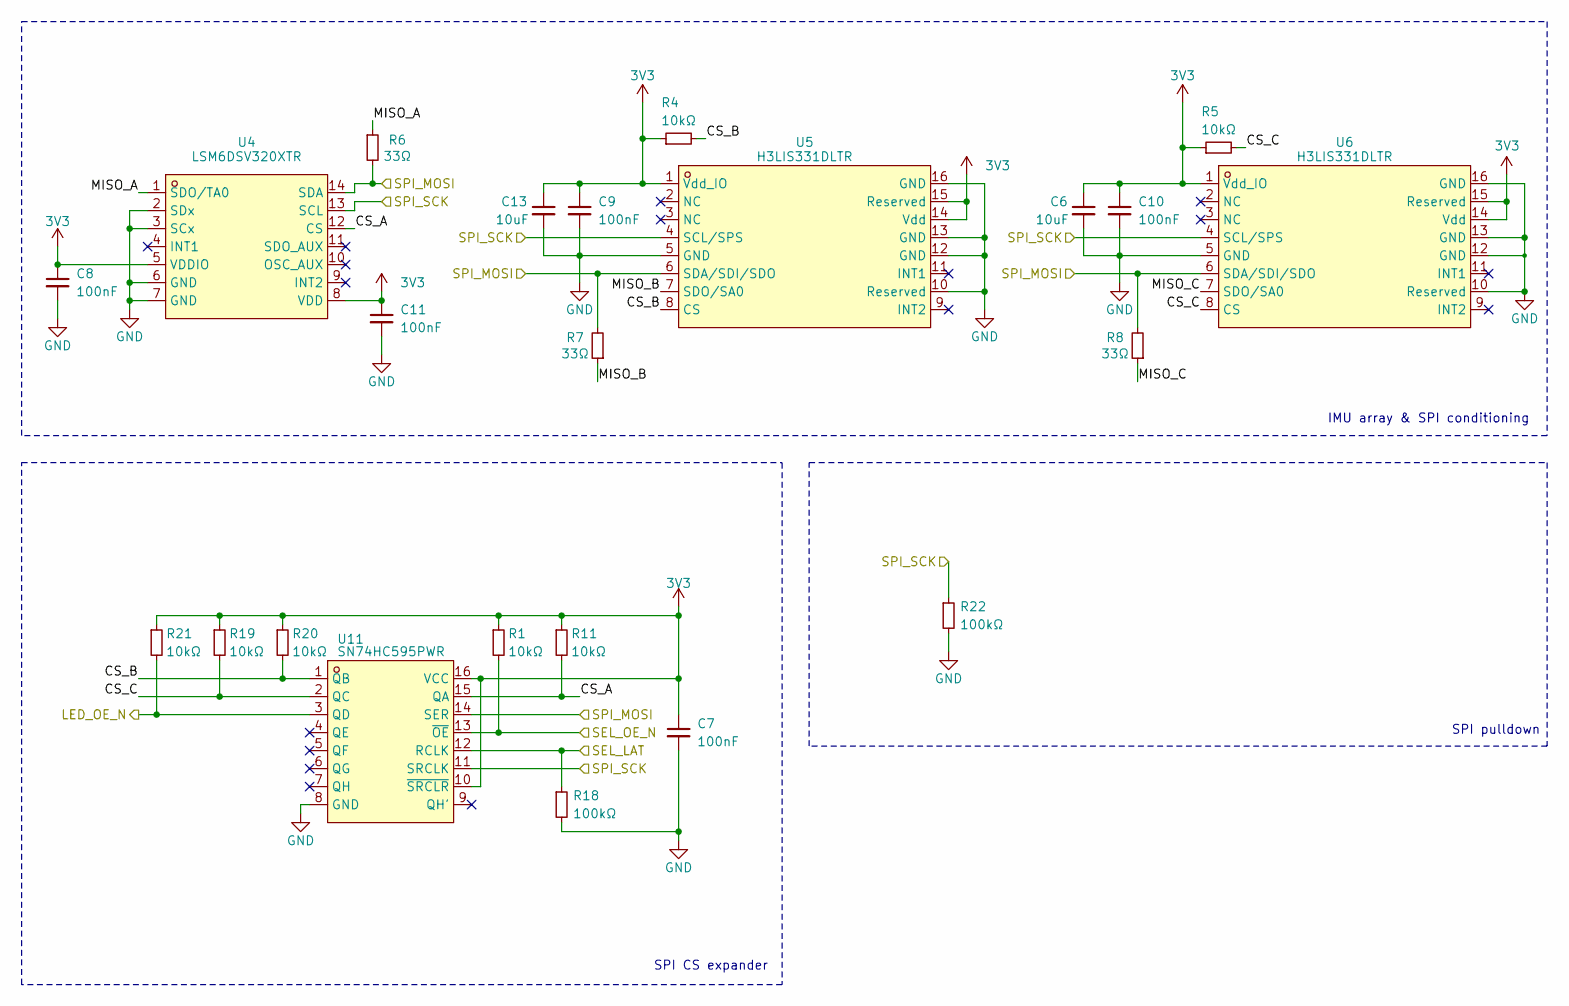
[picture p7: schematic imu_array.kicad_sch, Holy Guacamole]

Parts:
C6, C13: 10uF; C_0603_1608Metric; LCSC Part C913532
C7, C8, C9, C10, C11: 100nF; C_0402_1005Metric; LCSC Part C169834
R1, R4, R5, R11, R19, R20, R21: 10kΩ; R_0402_1005Metric; LCSC Part C844715
R6, R7, R8: 33Ω; R_0402_1005Metric; LCSC Part C3008986
R18, R22: 100kΩ; R_0402_1005Metric; LCSC Part C2077080
U4: LSM6DSV320XTR; LGA-14_L3.0-W2.5-P0.50-TL; LCSC Part C26633007
U5, U6: H3LIS331DLTR; LGA-16_L3.0-W3.0-P0.50-BL; LCSC Part C2655074
U11: SN74HC595PWR; TSSOP-16_L5.0-W4.4-P0.65-LS6.4-BL; LCSC Part C273642

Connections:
3V3: C6.1, C7.1, C8.1, C9.1, C10.1, C11.1, C13.1, R1.1, R4.1, R5.1, R11.1, R19.1, R20.1, R21.1, U4.5 (VDDIO), U4.8 (VDD), U5.1 (Vdd_IO), U5.14 (Vdd), U5.15 (Reserved), U6.1 (Vdd_IO), U6.14 (Vdd), U6.15 (Reserved), U11.10 (~SRCLR), U11.16 (VCC); also elsewhere on the board
/IMU Array/CS_A: R11.2, U4.12 (CS), U11.15 (QA)
/IMU Array/CS_B: R4.2, R20.2, U5.8 (CS), U11.1 (QB)
/IMU Array/CS_C: R5.2, R19.2, U6.8 (CS), U11.2 (QC)
/IMU Array/MISO_A: R6.1, U4.1 (SDO/TA0)
/IMU Array/MISO_B: R7.1, U5.7 (SDO/SA0)
/IMU Array/MISO_C: R8.1, U6.7 (SDO/SA0)
/LED_OE_N: R21.2, U11.3 (QD); also elsewhere on the board
/SEL_LAT: R18.1, U11.12 (RCLK); also elsewhere on the board
/SEL_OE_N: R1.2, U11.13 (~OE); also elsewhere on the board
/SPI_MOSI: R6.2, R7.2, R8.2, U4.14 (SDA), U5.6 (SDA/SDI/SDO), U6.6 (SDA/SDI/SDO), U11.14 (SER); also elsewhere on the board
/SPI_SCK: R22.1, U4.13 (SCL), U5.4 (SCL/SPS), U6.4 (SCL/SPS), U11.11 (SRCLK); also elsewhere on the board
GND: C6.2, C7.2, C8.2, C9.2, C10.2, C11.2, C13.2, R18.2, R22.2, U4.2 (SDx), U4.3 (SCx), U4.6 (GND), U4.7 (GND), U5.5 (GND), U5.10 (Reserved), U5.12 (GND), U5.13 (GND), U5.16 (GND), U6.5 (GND), U6.10 (Reserved), U6.12 (GND), U6.13 (GND), U6.16 (GND), U11.8 (GND); also elsewhere on the board

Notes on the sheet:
SPI pulldown
SPI CS expander
IMU array & SPI conditioning

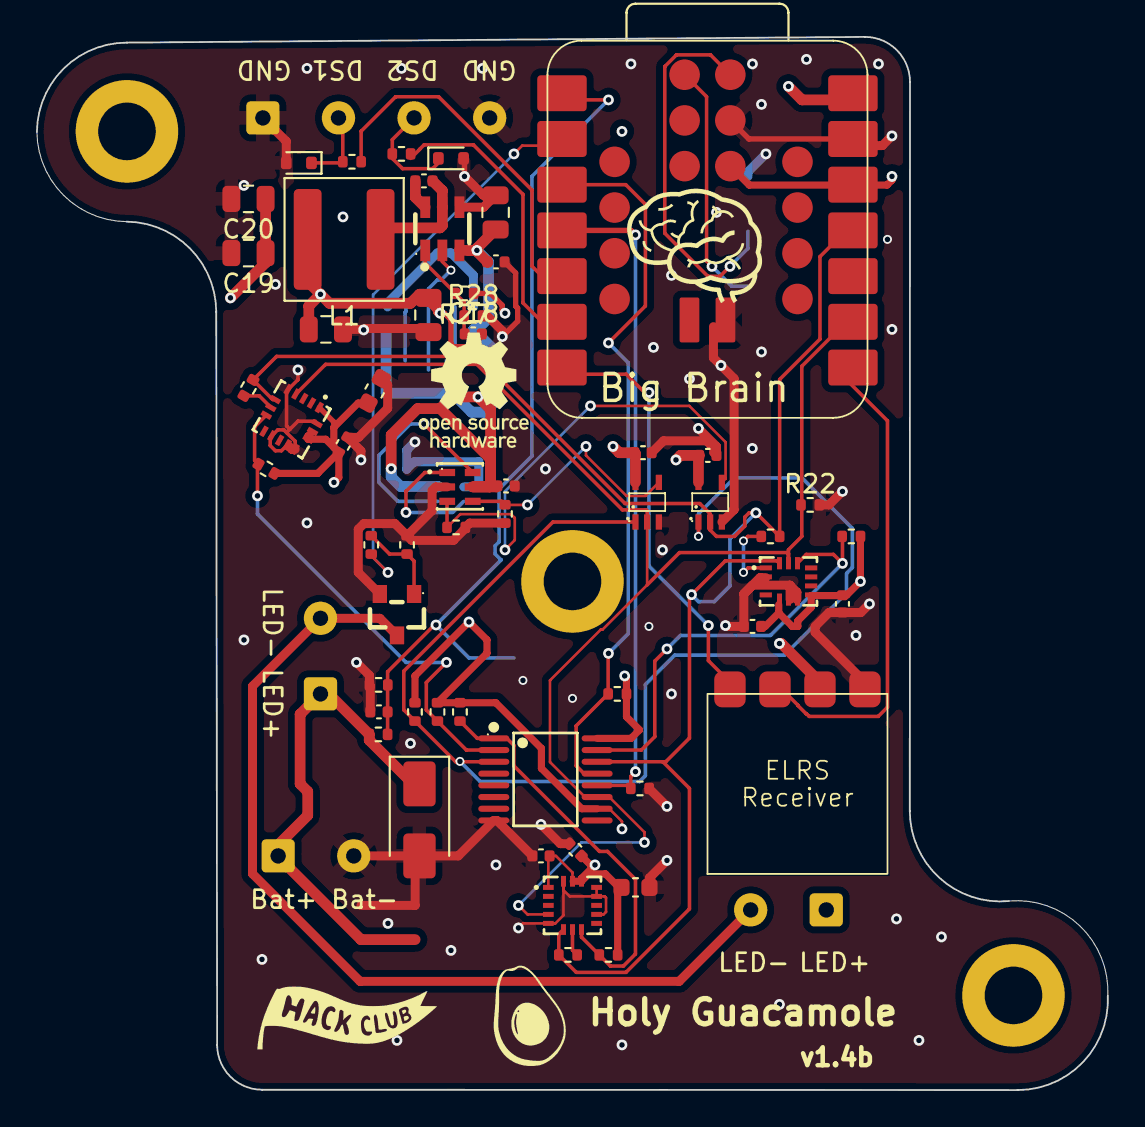
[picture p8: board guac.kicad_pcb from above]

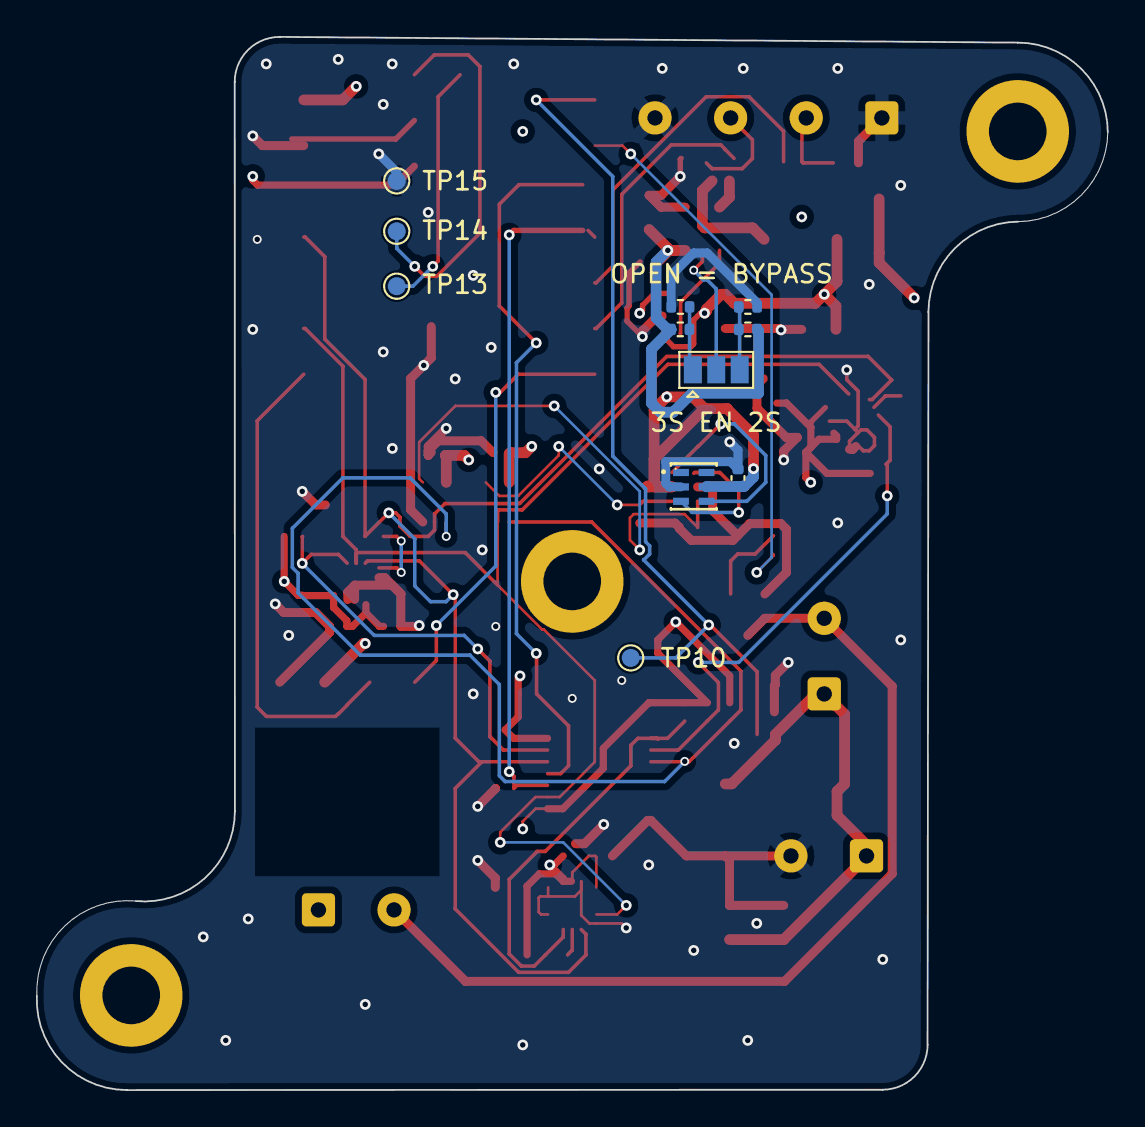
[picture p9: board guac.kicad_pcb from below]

Board: 4 copper layers, 59.5 x 58.5 mm, 75 parts (11 on the bottom side), 37 nets.

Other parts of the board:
MountingHole-2: MountingHole_3.2mm_M3_ISO7380_Pad
Mountinghole-2, Mountinghole-3: MountingHole_3.2mm_M3_ISO7380_Pad
gauc: LOGO

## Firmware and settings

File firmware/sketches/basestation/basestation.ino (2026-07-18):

/*
 * Basestation RF beacon (Arduino / XIAO ESP32-C6).
 *
 * The basestation is a dumb, stationary transmitter. Its only job is to
 * blast ESP-NOW broadcast packets as fast as the radio allows. It does not
 * read RSSI, does not talk to an ELRS receiver, and has no UART peripherals.
 *
 * The robot's onboard ESP32-C3 (esp-rssi) receives these broadcasts and
 * measures the RSSI of each packet. Because the robot spins, that RSSI rises
 * and falls once per revolution, and the robot derives its heading from the
 * phase of that signal. None of that happens here.
 *
 * The onboard user LED heartbeats (~1 Hz) while beaconing, so you can tell at
 * a glance that the basestation is powered and running.
 *
 * Board: Seeed XIAO ESP32-C6. Antenna + power only.
 * Requires the ESP32 Arduino core (any recent version).
 *
 * Protocol: ESP-NOW broadcast on a fixed channel, no encryption, no ACK.
 * Payload = {magic=0xB6, uint32 seq}. The payload is irrelevant to the
 * heading math (that only uses received RSSI); seq is for drop diagnostics.
 * Channel and magic must match esp-rssi.
 */

#include <WiFi.h>
#include <esp_now.h>
#include <esp_wifi.h>

#define ESPNOW_CHANNEL  1
#define BEACON_MAGIC    0xB6

// XIAO ESP32-C6 user LED: GPIO15, active-low (LOW = on).
#define LED_PIN         LED_BUILTIN
#define LED_ON          LOW
#define LED_OFF         HIGH

static const uint8_t broadcast_mac[6] = {0xFF, 0xFF, 0xFF, 0xFF, 0xFF, 0xFF};

typedef struct __attribute__((packed)) {
  uint8_t  magic;   // BEACON_MAGIC, lets the robot filter foreign traffic
  uint32_t seq;     // rolling counter for drop detection / diagnostics
} beacon_pkt_t;

static beacon_pkt_t pkt = { BEACON_MAGIC, 0 };

void setup() {
  Serial.begin(115200);
  pinMode(LED_PIN, OUTPUT);
  digitalWrite(LED_PIN, LED_ON);   // solid during bring-up
  delay(100);
  Serial.println("Basestation RF beacon starting");

  // STA mode, no AP association; lock the channel and kill power save so
  // packets go out back-to-back and the robot sees consistent RSSI.
  WiFi.mode(WIFI_STA);
  WiFi.disconnect();
  esp_wifi_set_ps(WIFI_PS_NONE);
  esp_wifi_set_channel(ESPNOW_CHANNEL, WIFI_SECOND_CHAN_NONE);

  if (esp_now_init() != ESP_OK) {
    Serial.println("ESP-NOW init failed; rebooting");
    delay(1000);
    ESP.restart();
  }

  esp_now_peer_info_t peer = {};
  memcpy(peer.peer_addr, broadcast_mac, sizeof(broadcast_mac));
  peer.channel = ESPNOW_CHANNEL;
  peer.encrypt = false;
  if (esp_now_add_peer(&peer) != ESP_OK) {
    Serial.println("ESP-NOW add_peer failed; rebooting");
    delay(1000);
    ESP.restart();
  }

  Serial.printf("Ready - broadcasting beacon on channel %d\n", ESPNOW_CHANNEL);
}

void loop() {
  // Fire as fast as the TX queue drains. When it's full esp_now_send returns
  // an error; back off a hair and retry. This paces us to the link rate
  // without needing a send-complete callback (whose signature has churned
  // across ESP32 core versions).
  esp_err_t ret = esp_now_send(broadcast_mac, (uint8_t *)&pkt, sizeof(pkt));
  if (ret == ESP_OK) {
    pkt.seq++;
  } else {
    delayMicroseconds(200);
  }

  // Heartbeat: toggle the LED ~1 Hz so "blinking" means alive and beaconing.
  static uint32_t last_blink = 0;
  static bool lit = true;
  uint32_t now = millis();
  if (now - last_blink >= 500) {
    last_blink = now;
    lit = !lit;
    digitalWrite(LED_PIN, lit ? LED_ON : LED_OFF);
  }
}

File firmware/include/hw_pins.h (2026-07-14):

#pragma once

/*
 * Holy Guacamole carrier PCB pin assignments.
 * Single source of truth matching circuit.py / spec.md pin table.
 */

/* SPI bus (shared: IMUs + SN74HC595 latch + SK9822 buffer inputs) */
#define PIN_SPI_SCK   2   /* XIAO D8/GPIO2 */
#define PIN_SPI_MOSI  3   /* XIAO D10/GPIO3 */
#define PIN_SPI_MISO  4   /* XIAO D9/GPIO4 */
#define SPI_INST      spi0

/* SN74HC595 latch control */
#define PIN_SEL_OE_N  42  /* XIAO D2/A2/GPIO42, active-low output enable */
#define PIN_SEL_LAT   43  /* XIAO D3/A3/GPIO43, latch clock */

/* Latch bit assignments (active-low outputs) */
#define LATCH_BIT_CS_A     0  /* QA / pin 15 -> CS_A */
#define LATCH_BIT_CS_B     1  /* QB / pin 1  -> CS_B */
#define LATCH_BIT_CS_C     2  /* QC / pin 2  -> CS_C */
#define LATCH_BIT_LED_OE_N 3  /* QD / pin 3  -> LED_OE_N */

/* Safe latch image: all outputs inactive (high) */
#define LATCH_SAFE  0xFF

/* DSHOT bidirectional (direct RP2350 GPIO, not through latch) */
#define PIN_DSHOT1    6   /* XIAO D4/SDA/GPIO6 -> AM32 ch1 */
#define PIN_DSHOT2    7   /* XIAO D5/SCL/GPIO7 -> AM32 ch2 */

/* CRSF UART to ELRS receiver */
#define PIN_CRSF_TX   0   /* XIAO D6/TX/GPIO0 */
#define PIN_CRSF_RX   1   /* XIAO D7/RX/GPIO1 */
#define CRSF_UART     uart0
#define CRSF_BAUD     420000

/* Battery voltage sense */
#define PIN_VBAT_ADC  40  /* XIAO A0/D0/GPIO40 */
#define ADC_VBAT_CHAN 0   /* ADC channel for GPIO40 */

/* Heading LED MOSFET gate */
#define PIN_HEAD_LED  41  /* XIAO A1/D1/GPIO41 */

/* SWD debug (repurposed for ESP32 UART in first-rev bodge;
 * SWD not used in production. Heading LED GPIO41 is DNP.) */
#define PIN_SWDIO     23   /* ESP32 TX -> RP2350 RX */
#define PIN_SWDCK     24   /* ESP32 RX -> RP2350 TX */

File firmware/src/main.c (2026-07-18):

#include <stdio.h>
#include <string.h>
#include <math.h>

#include "pico/stdlib.h"
#include "pico/multicore.h"
#include "hardware/sync.h"
#include "hardware/pio.h"

#include "hw_pins.h"
#include "estimation/heading_estimate.h"
#include "dshot/dshot.h"
#include "crsf/crsf.h"
#include "sensor/sensor_dispatch.h"
#include "app/control_loop.h"
#include "safety/watchdog.h"
#include "safety/battery.h"
#include "safety/rc_health.h"
#include "led/head_led.h"
#include "rc_map.h"

#define RAD_TO_DEG 57.2958f
#define CRSF_LINK_TIMEOUT_MS 500
#define STATUS_PRINT_INTERVAL_MS 100
#define CONTROL_LOOP_SLEEP_US 500

/* ---- Shared estimate (core 0 → core 1) ---- */

typedef struct {
    heading_estimate_t est;
    uint32_t timestamp_us;
    volatile bool ready;
} shared_estimate_t;

static shared_estimate_t shared_est;
static spin_lock_t *est_lock;
static app_config_t app_cfg;

static bool is_safe_to_arm(const crsf_state_t *rc) {
    return crsf_link_alive(rc, CRSF_LINK_TIMEOUT_MS)
        && rc_health_ok()
        && battery_ok()
        && rc_switch_high(rc->channels[RC_CH_ARM]);
}

/* ---- Core 1: Control (DSHOT + CRSF) ---- */

static void core1_control_loop(void) {
    if (!dshot_load_program(pio0)) printf("DSHOT PIO program load failed\n");

    dshot_esc_t esc1, esc2;
    if (!dshot_init(&esc1, pio0, PIN_DSHOT1)) printf("DSHOT1 init failed\n");
    if (!dshot_init(&esc2, pio0, PIN_DSHOT2)) printf("DSHOT2 init failed\n");

    crsf_init();
    rc_health_init();
    head_led_init();
    crsf_state_t rc = {0};

    printf("Core 1 ready [%s]. Waiting for RC link...\n", sensor_primary.name);

    uint32_t c1_last_us = time_us_32();

    while (1) {
        crsf_poll(&rc);
        rc_health_update(rc.channels);

        /* Read latest estimate from core 0. */
        heading_estimate_t est = {0};
        uint32_t irq = spin_lock_blocking(est_lock);
        if (shared_est.ready) {
            est = shared_est.est;
            shared_est.ready = false;
            head_led_on_estimate(&est, time_us_32());
        }
        spin_unlock(est_lock, irq);

        app_command_t cmd = {0};
        cmd.armed = is_safe_to_arm(&rc);
        cmd.mode = rc_mode(rc.channels[RC_CH_MODE]);
        cmd.attack = rc_switch_high(rc.channels[RC_CH_ATTACK]);
        cmd.speed = RC_SPEED_ARMED;   /* no throttle stick: preset spin power */
        /* DRIFT mode actually translates; STOP/SPIN do not. */
        app_cfg.drift_enabled = (cmd.mode == DRIVE_MODE_DRIFT);
        if (cmd.armed) {
            /* Translation is the right stick (X=left/right, Y=fwd/back). */
            cmd.stick_x = (float)((int16_t)rc.channels[RC_CH_STICK_X] - CRSF_CH_MID) /
                          (float)(CRSF_CH_MAX - CRSF_CH_MID);
            cmd.stick_y = (float)((int16_t)rc.channels[RC_CH_STICK_Y] - CRSF_CH_MID) /
                          (float)(CRSF_CH_MAX - CRSF_CH_MID);
        }

        uint32_t c1_now_us = time_us_32();
        float c1_dt = (float)(c1_now_us - c1_last_us) * 1e-6f;
        c1_last_us = c1_now_us;

        /* Left stick X nudges the heading reference ("front"), matching the
         * sim. Heading isn't absolutely observable, so this is a live trim. */
        float trim_in = (float)((int16_t)rc.channels[RC_CH_TRIM] - CRSF_CH_MID) /
                        (float)(CRSF_CH_MAX - CRSF_CH_MID);
        if (fabsf(trim_in) > 0.15f)
            app_cfg.heading_trim -= trim_in * 2.0f * c1_dt;

        app_motors_t m = app_control_tick(&app_cfg, &cmd, &est, c1_dt);

        dshot_set_throttle(&esc1, m.throttle_a);
        dshot_set_throttle(&esc2, m.throttle_b);

        dshot_read_telemetry(&esc1);
        dshot_read_telemetry(&esc2);

        static uint32_t last_print = 0;
        uint32_t now = to_ms_since_boot(get_absolute_time());
        if (now - last_print > STATUS_PRINT_INTERVAL_MS) {
            last_print = now;
            printf("hdg=%6.1f° w=%7.1f RPM=%lu/%lu a/b=%.2f/%.2f %s%s%s\n",
                   (double)(est.heading * RAD_TO_DEG), (double)est.omega,
                   (unsigned long)esc1.telemetry.rpm,
                   (unsigned long)esc2.telemetry.rpm,
                   (double)m.throttle_a, (double)m.throttle_b,
                   cmd.armed ? "LINK" : "NO-LINK",
                   battery_low() ? " LOW-BAT" : "",
                   !rc_health_ok() ? " STALE-RC" : "");
        }

        head_led_tick(time_us_32());

        watchdog_feed_core1();
        sleep_us(CONTROL_LOOP_SLEEP_US);
    }
}

/* ---- Core 0: Sensor acquisition (main) ---- */

int main(void) {
    stdio_init_all();
    printf("Holy Guacamole firmware starting [%s]...\n", sensor_primary.name);

    app_config_default(&app_cfg);

    int lock_num = spin_lock_claim_unused(true);
    est_lock = spin_lock_instance(lock_num);

    battery_init();

    /* Primary sensor must init first (owns EKF in fusion mode). */
    if (!sensor_primary.init()) {
        printf("%s init failed\n", sensor_primary.name);
        while (1) tight_loop_contents();
    }

    /* Auxiliary sensor (e.g., RSSI fusion into IMU EKF). */
    if (sensor_aux) {
        if (!sensor_aux->init())
            printf("%s aux init failed (continuing without)\n", sensor_aux->name);
        else
            printf("Aux sensor: %s\n", sensor_aux->name);
    }

    watchdog_start(2000);
    multicore_launch_core1(core1_control_loop);

    uint32_t last_us = time_us_32();

    while (1) {
        uint32_t t = time_us_32();
        float dt = (float)(t - last_us) * 1e-6f;
        last_us = t;

        heading_estimate_t est = sensor_primary.tick(dt);

        uint32_t irq = spin_lock_blocking(est_lock);
        shared_est.est = est;
        shared_est.timestamp_us = t;
        shared_est.ready = true;
        spin_unlock(est_lock, irq);

        battery_sample();
        watchdog_feed();
        busy_wait_until(t + 1000);  /* 1kHz sensor cadence */
    }
}

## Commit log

2026-06-26 feat: git init
    [circuit.kicad_pcb, circuit.kicad_sch]
2026-06-29 feat: almost full schematic
    [circuit.kicad_sch, power.kicad_sch]
2026-06-29 feat: organize into hierarchical sheets
    [circuit.kicad_sch, imu_array.kicad_sch, status_led.kicad_sch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]
2026-06-29 feat: organize subsheets
    [imu_array.kicad_sch, power.kicad_sch, status_leds.kicad_sch]
2026-06-30 feat: organize into better sheets
    [imu_array.kicad_sch, power.kicad_sch]
2026-07-01 feat: swap to the 74HC595 for cs expansion
    [circuit.kicad_sch, imu_array.kicad_sch, power.kicad_sch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]
2026-07-04 feat: first bit of routing and double leds + fixes
    [circuit.kicad_pcb, circuit.kicad_sch, power.kicad_sch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]
2026-07-04 feat: pcb routing
    [circuit.kicad_pcb]
2026-07-04 feat: 4 layer route
    [circuit.kicad_pcb, status_leds.kicad_sch]
2026-07-04 feat: add stiching vias
    [circuit.kicad_pcb]
2026-07-05 feat: add more vias
    [circuit.kicad_pcb]
2026-07-06 feat: add bom
2026-07-06 feat: add cad
    [body.step, lid.step]
2026-07-06 feat: add bom placement
    [circuit.kicad_pcb, circuit.kicad_sch, imu_array.kicad_sch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]
2026-07-06 feat: add pulldown resister and note mode 0
    [circuit.kicad_pcb, imu_array.kicad_sch]
2026-07-08 feat: review from tyler + align circuit.py
    [circuit.kicad_pcb, imu_array.kicad_sch, power.kicad_sch]
2026-07-08 feat: add watchdog, bat low, and pid
2026-07-08 feat: add jumper for shutoff voltage
    [circuit.kicad_pcb, power.kicad_sch]
2026-07-08 feat: make 3d models work
    [circuit.kicad_pcb]
2026-07-08 chore: swap holes to the other side
    [circuit.kicad_pcb]
2026-07-09 feat: extend pcb to fit better in cad
    [circuit.kicad_pcb, power.kicad_sch]
2026-07-09 docs: update cad image
2026-07-09 bug: fix lcsc inductor part number
    [circuit.kicad_pcb, power.kicad_sch]
2026-07-09 feat: update bom
    [bom.csv]
2026-07-10 feat: update kicad project name to guac
    [guac.kicad_pcb, guac.kicad_sch, imu_array.kicad_sch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]
2026-07-10 feat: add impulse to collisions
    [plant.c]
2026-07-10 feat: per imu curve and fix control loop
    [accel_cal.h, main.c]
2026-07-11 docs: update pcb images
    [guac.kicad_pcb]
2026-07-12 chore: update bom
    [bom.csv]
2026-07-13 feat: update cad image and silkscreen
    [guac.kicad_pcb]
2026-07-13 feat: update cad
    [body.step, lid.step, toothie.dxf]
2026-07-13 feat: update pcb to use new components
    [digikey_upload_3boards.csv, guac.kicad_pcb, mouser_user_confirmed_3boards.csv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]
2026-07-14 feat: add switchable sensors support
2026-07-15 feat: add cern license bit to kicad
    [guac.kicad_pcb, guac.kicad_sch]
2026-07-17 feat: add RP2350 bench tools for receiver flashing and motor checkout
    Two temporary tool firmwares to speed up bring-up, separate from the
    flight firmware:
    - ELRS passthrough: makes the board act as a Betaflight-style serial
    bridge so the ELRS receiver can be flashed or configured over USB
    with no adapter, transmitter, or WiFi.
    - Motor/channel bench test: spins each motor independently at a low
    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
2026-07-18 feat: add blinking led
2026-11-03 feat: rev 2 carrier schematic, spec, and board outline
    Turn the carrier into the power distribution board (XT30 battery and
    switch loop, ESC feed pads, bulk cap), move to latching JST-GH
    connectors, take the ELRS receiver off-board, and drop the SK9822
    status LEDs and duplicate pull-ups. Fixes the Rev A bug where the IMU
    data lines went to MOSI instead of MISO.
    Adds a 40 x 76 mm outline and keepouts derived from chassis v33 rev B,
    and rewrites the spec for the 3S HV pack and the new layout.
    💘 Generated with Crush
    Assisted-by: Crush:claude-opus-5-5
2026-11-04 feat: fit the rev 2 carrier to chassis v3.4c
    Move the south mounting holes out for a thicker wall to the wire groove
    and re-place parts around the new battery, ribs and cross-beam: both
    XT30s turn 90 degrees, the ESC power pads move south of the beam and
    become SMD lap pads, the bulk cap becomes a low-profile polymer part
    that fits under the battery, and the two heading LEDs share one
    connector. Only the two XT30s remain through-hole.
    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
2026-11-04 feat: turn the LED connector north so the harness clears the IMU
    The v3.4d harness ran its Y-splice over the outer accelerometer, and
    with the connector opening east there was no room to route around it.
    The connector now opens north, with its plug and splice under the motor
    key sweep, 4 mm or more from any IMU. Harness wire zones are now hard
    obstacles in the IMU rotation scan so this cannot pass silently again,
    and the 166 degree rotation is pinned so firmware angles stop drifting.
    Carries the v3.4d J4/J5 courtyard split and J1 footprint note.
    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
2026-11-05 feat: lay out the rev 2 carrier board with real XT30 connectors
    Place and route the rev 2 board from scripts so the layout can be
    rebuilt, and centre it on the sheet. The battery and switch-loop XT30s
    now use the AMASS male and female footprints with the vendor 3D models,
    so connector height and polarity show up correctly in the chassis fit.
    The ground pour refill after the move left the regulator's ground pad
    floating; a short track to a via under the chip ties it back in.
    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
2026-11-05 chore: add a larger gap between powerplanes
2026-11-06 chore: shift vias and ground return
2026-11-10 feat: reroute pcb to fit pcbway reqs
2026-11-10 chore: clear out rev A leftovers from the hardware and docs
    Remove the old SKiDL sketch, the orphaned SK9822 schematic sheet, the
    rev A interactive BOM and JLC plugin settings, and unused footprints,
    symbols and 3D models. Replace the rev A DigiKey/Mouser carts with one
    rev 2 BOM, add a one-command PCBWay export, and stop tracking the CAD
    cross-sections, which the cad/rev2 scripts regenerate. The spec pin
    table now lists RP2350 GPIO numbers, and the braindump is marked as
    superseded by the spec.
    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
2026-11-10 fix: drive the rev 2 carrier's real pins and give the heading LED a hard duty cap
    The XIAO RP2350 is an RP2350A, so D0-D3 are GPIO 26/27/28/5, not
    40-43; battery sense, the heading LED and the CS latch were wired to
    pins that do not exist. Builds now target the XIAO board (2 MB flash)
    instead of the Pico 2. The heading LED moves to a PIO one-shot that
    caps duty at 25% and pulse length in hardware, strobes 400 us per
    revolution when spinning, and blinks the spec's status codes when
    still. The ESP32 RSSI experiment and other dead code are removed.
    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
2026-11-10 fix: keep the ESC current in the south end of the carrier
    The switch-loop XT30 moves to the SW corner as a mirror of the battery
    XT30 (chassis v3.4g), so the motor current no longer detours up the E
    edge and across the N end past an IMU and under the XIAO. Battery and
    switched power now run stacked on top of each other straight across
    the S end, which cuts the board copper in that path from about 10 to
    3.4 mOhm, and the signals that cross it go through short inner-layer
    lanes. The LED connector takes the old switch spot, the stackup now
    matches the 1.6 mm, 2 oz order, and the board gets a dense GND
    stitching grid.
    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
2026-11-10 fix: pull the heading LED driver clear of the north clamp ledge
    R16 and R17's pads reached 0.08 mm into the no-parts strip under the N
    clamp ledge. They and Q1 move 0.15 mm south, and the board is rerouted.
    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
2026-11-10 chore: keep the power-layout review and its resistance solver in the repo
    Adds the chassis session's handoff for the v3.4g power move and the
    scripts it used to read the board and solve the DC resistance of a
    power path, so the 3.3 mOhm figure can be re-checked after any layout
    change. Taken from the chassis-v34g-j7-sw branch without its CAD
    changes, which main already has in an updated form.
    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
2026-11-11 feat: make the carrier 3S-only and merge the silkscreen art
    The UVLO select jumper and the 2S divider are gone from the schematic
    and board; the 3S divider (now 66.5k, cutting at about 8 V) feeds the
    buck's EN directly. The silk-art branch is merged, the art stage now
    runs from the routing pipeline, and its via-clearing step respects the
    hole-clearance and edge rules so the board passes DRC with no
    warnings at all. The parts list follows.
    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
2026-11-11 feat: line the back-side test pads up along the blueprint ring
    The four probe pads (SWD, GND, battery sense) sit in one tilted row on
    the r 15 arc between the two blueprint rings, with their labels turned
    to match, instead of scattered under the XIAO. The four ESD-clamp to
    connector hops are now drawn by hand, and the bridge stage repeats
    until nothing is left open, so a routing run no longer ends with one
    stray unconnected net.
    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
2026-11-11 fix: make the IMU driver talk to the real sensors and arm on purpose
    The accelerometer driver could not have worked on the board: the chip
    select byte was sent bit-reversed, chip select stayed low across
    several register accesses, and the main IMU was set up with an older
    part's register map. The two high-g parts were also left at half
    range. All three sensors are now configured from their datasheets,
    each chip's axes are mapped to radial and tangential, and the driver
    can check its own configuration while running.
    The robot no longer spins up by itself. Arming needs the switch to be
    seen low and then raised while everything is healthy; link loss, a
    stale heading estimate or a flat battery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
2026-11-11 fix: send every crossing signal through the tunnel and gate the fab export
    Two of the eight signals that cross the south power band were going
    the long way round, past the switch pins, instead of through their
    inner-layer lanes. That route is now closed, the tight fan-outs at
    both ends of the tunnel are drawn by hand, and ground return vias sit
    next to the lanes at each end. No via hole lands in or against a
    solder pad any more, and tracks the autorouter leaves too close to
    other copper are relaid.
    The board pipeline can be rerun from the schematic without crashing
    or doubling its own copper, and it carries the schematic's assembly
    flags and fields onto the board, so the parity check is dow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
2026-11-11 docs: bring the spec and CAD notes up to chassis v3.4g
    The spec still described the v3.4f chassis, strain-relief slots the
    board does not have, and XIAO underside pads as unconnected when they
    carry SWD, ground and 3V3. Those are corrected, along with stale
    numbers in the firmware notes, the power figures after today's
    reroute (3.3 mOhm end to end), and markers on the documents that
    describe the old Rev A board. The CAD README now leads with the
    current chassis and keeps older proposals under a history heading.
    The README gains a short map of the repo and how to rebuild the
    board. The generated chassis cross-sections are no longer tracked.
    Assisted-by: Crush:claud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
2026-11-12 feat: fill the bare ends of the second inner layer with ground
    The second inner layer had no copper at the north and south ends of
    the board, leaving it at 63% copper against 90% on the other inner
    layer. A low-priority ground pour now takes whatever the power rails
    leave, which brings it to 82% and evens the two layers up.
    The spec and script comments no longer claim the battery band is
    doubled on that layer: the two pieces there each hang on one
    connector pin and carry no current. They stay because they keep the
    3.3 V plane out from under the battery band.
    Assisted-by: Crush:claude-fable-5-2
    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

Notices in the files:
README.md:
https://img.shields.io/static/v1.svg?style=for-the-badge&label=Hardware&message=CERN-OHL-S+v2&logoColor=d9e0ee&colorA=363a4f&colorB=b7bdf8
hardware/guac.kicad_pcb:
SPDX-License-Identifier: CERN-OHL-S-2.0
